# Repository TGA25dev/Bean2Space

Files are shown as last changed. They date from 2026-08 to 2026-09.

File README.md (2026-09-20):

# Bean2Space 🚀
> HRC-01: the first rocket of the Bean2Space program. A 3D printed DIY rocket powered by an ESP32-S3 flight computer running MicroPython. Featuring telemetry logging, a ground station and a trigger system.<br><br>
Also my submission to the [Stardance Challenge](https://stardance.hackclub.com/)!

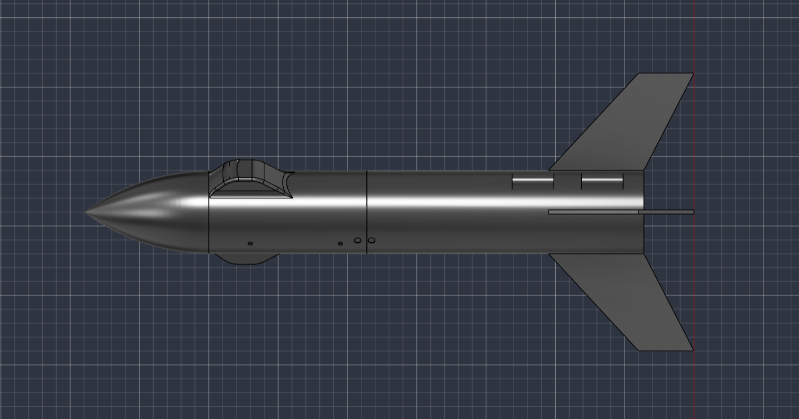
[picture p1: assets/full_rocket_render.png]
Banner


## Overview
This project is basically made of three main components:
- **The flight computer**: An ESP32-S3 running micropython. Reads temperature and pressure from the BMP280 and gyroscope/accelerometer data from an MPU6050. Both via I2C. Also transmits live telemetry to the ground station using ESPNOW protocol. *In other terms : the brain of this project*
- **The ground station**: A simple ESP32-C3 that receives the telemetry packets and logs them *(more features to come later)*
- **The trigger Station**: A wired ignition trigger. Uses AA batteries, a safety key and a *red* trigger button.

## CAD and Hardware Design
### Source files and visuals
> All the CAD work has been done in **Fusion 360** but some initial .obj files have been imported from **[OpenRocket](https://openrocket.info/)**. 

- **Nose cone + bottom closure:**<br>
The nose cone has a hole on the bottom to add extra weight if ever needed. The bottom closure part closes the hole and is sealed using tape.

   [Download nose_cone.step](cad/rocket/nose_cone.step)
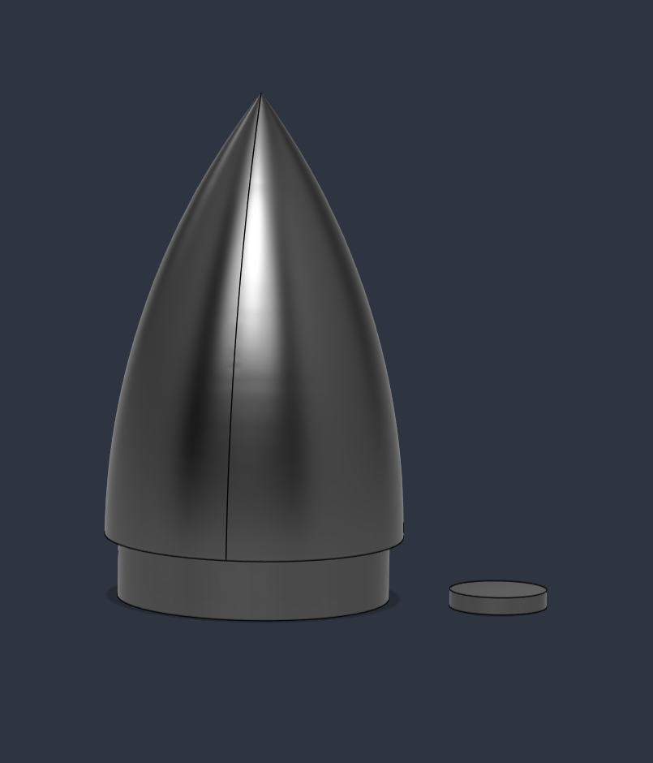
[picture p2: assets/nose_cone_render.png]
nose_cone_file
   

---

- **Main Stage**:<br>
The main stage has two pods on both sides to add a small camera (SQ11 size), M3 screw holes to attach the inner rack (see below) with guide rails inside, 3 static port holes and finally an alignment hole to properly align main and engine stage.

   [Download main_stage.step](cad/rocket/main_stage.step)
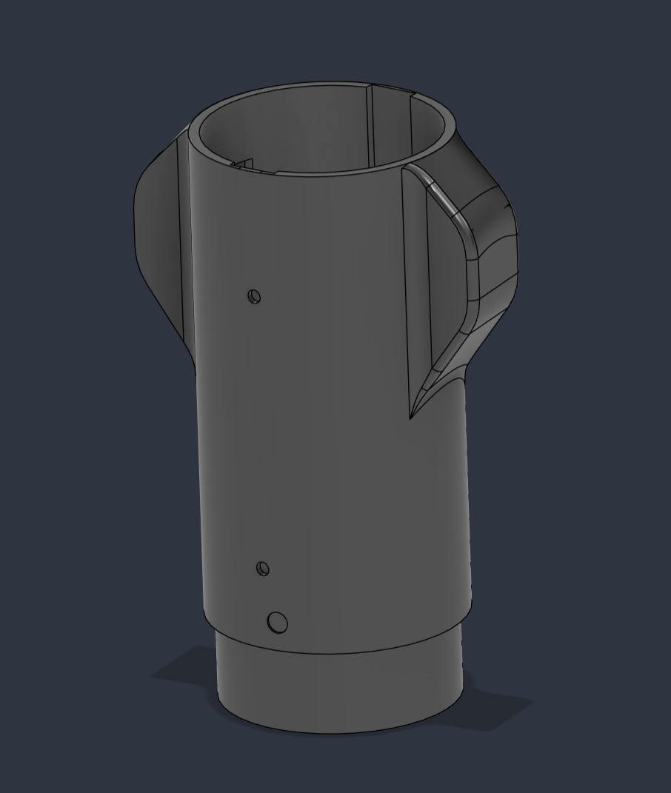
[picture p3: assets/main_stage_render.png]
main_stage_file
   

---

- **Instruments Rack**:<br> 
The rack is slid in the stage's guide rails and secured with 4 M3 screws on the sides using inserts. The board is placed on one side and also secured with M3 screws while on the other side is the battery slot secured with velcro. On top there's a small handle to easily pull off the rack from the rocket.

   [Download instruments_rack.step](cad/rocket/instruments_rack.step)
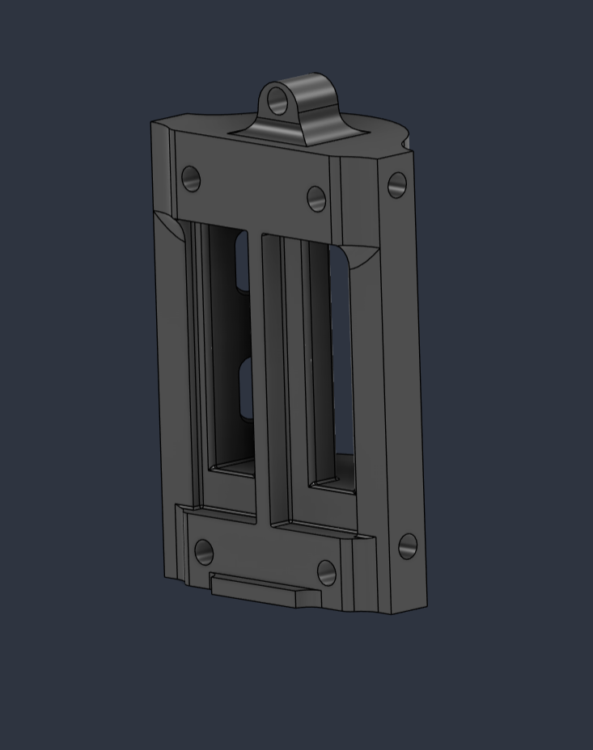
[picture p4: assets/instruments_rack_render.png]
instruments_rack_file
   

---

- **Shock Cord Mount**:<br>
Two of those mounts are placed on the bottom of the main stage shoulder and glued with epoxy. A long screw is slid between both holes with a nut at the end. Finally the shock cord is tied to the screw.

   [Download shock_cord_mount.step](cad/rocket/shock_cord_mount.step)
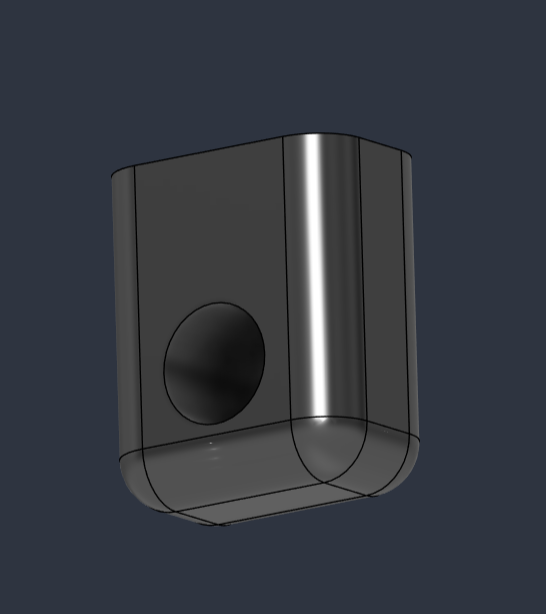
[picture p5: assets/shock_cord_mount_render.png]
shock_cord_mount_file
   

---

- **Engine Stage**:<br>
The engine is slid in the 18mm hole on the bottom. The stage has two 6mm diameter launch lugs where you can slide the launch rod. On the bottom in the inside of the tube 4 holes allow you to tie the shock cord.

   [Download engine_stage.step](cad/rocket/engine_stage.step)
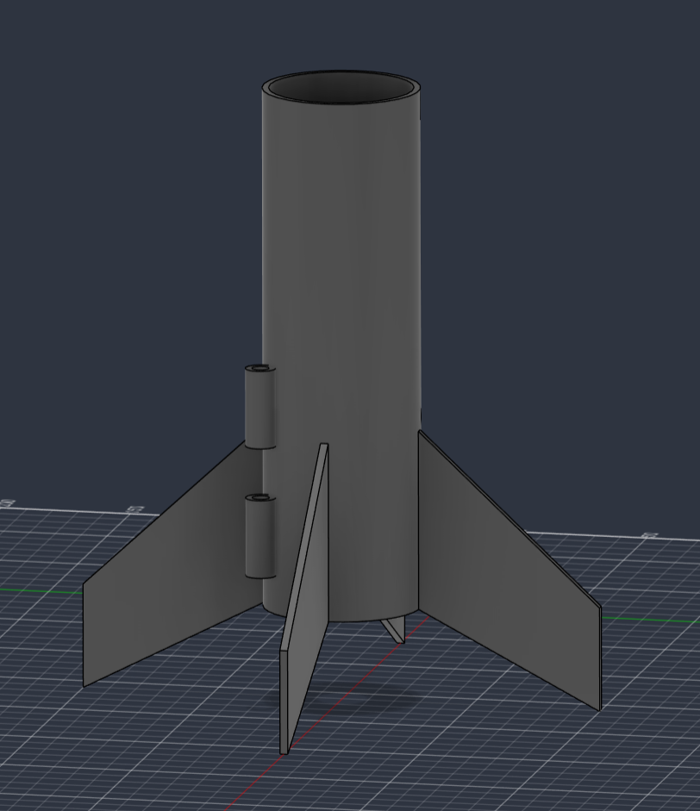
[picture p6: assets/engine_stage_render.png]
engine_stage__file
   

---

- **Trigger Box Cover**:<br>
Here there are 3 holes, one for an led, another for the security key and a third one for the launch button.

   [Download trigger_box_cover.step](cad/trigger_station/trigger_box_cover.step)
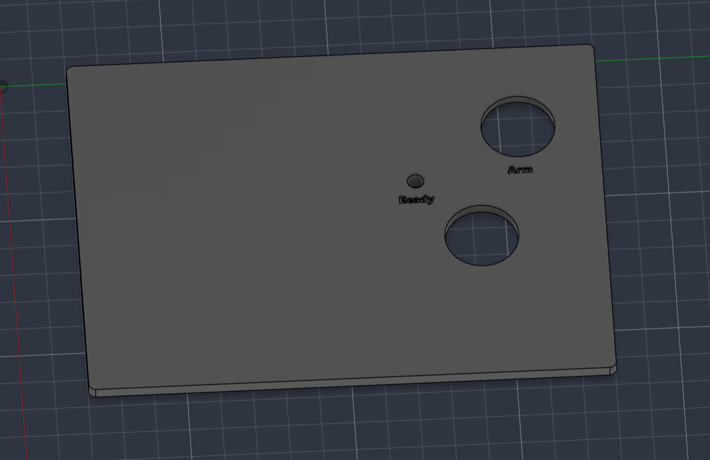
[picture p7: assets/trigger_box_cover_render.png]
trigger_box_cover
   

---

- **Trigger Box Body**:<br>
The box has a support to add velcro to it and put the two battery holders. It also has a hole to fit the ignition cable through it.

   [Download trigger_box_body.step](cad/trigger_station/trigger_box_body.step)
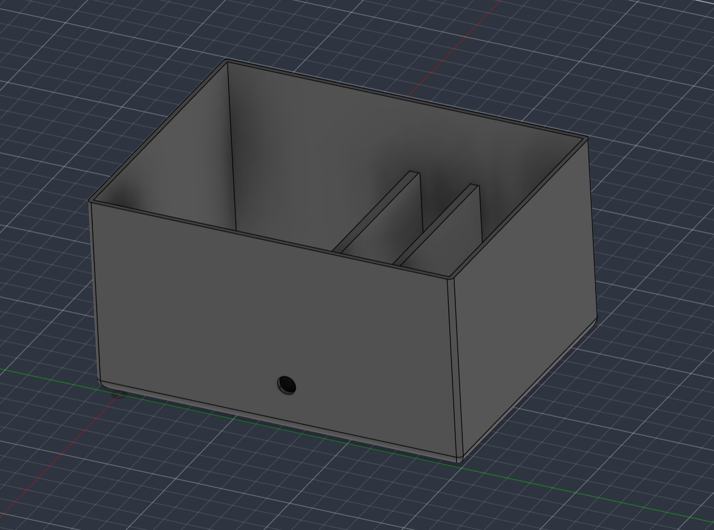
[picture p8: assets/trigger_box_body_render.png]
trigger_box_body
   

### Wiring diagrams

### Flight computer
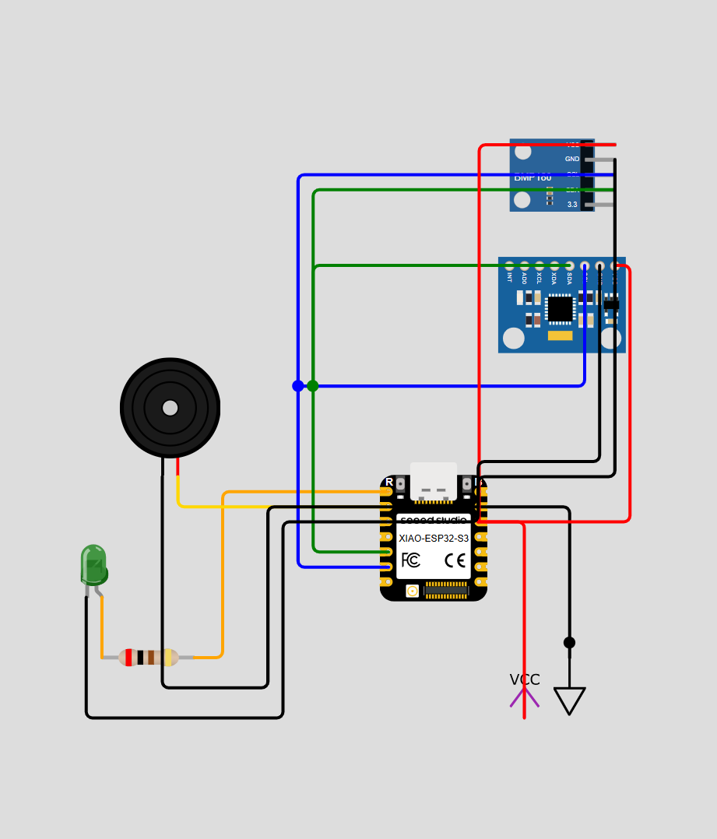
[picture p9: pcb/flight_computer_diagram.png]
flight_computer_diagram


| Component | Component Pin | ESP32 Pin |
| :--- | :--- | :--- |
| **BMP280 & MPU6050** | VCC | 3.3V |
| | GND | GND |
| | SDA | GPIO5 (D4) |
| | SCL | GPIO6 (D5) |
| **Buzzer** | Signal (+) | GPIO4 (D3) |
| | (-) | GND |
| **Status LED** | Anode (+) | GPIO1 (D0) |
| | (-) | GND |

### Trigger Station
trigger_station_diagram

## Firmware 
Both the ESP32 S3 and C3 run MicroPython. Use [`esptool`](https://docs.espressif.com/projects/esptool/en/latest/esp32/) to flash them.

1. Flash the correct MicroPython version for each of the boards
2. - **ESP32-S3 (flight computer):** Upload everything in the `/firmware` folder onto the board (if possible don't upload the `/ground_station` folder as it will be useless for this board).

   - **ESP32-C3 (ground station)**: Upload all the files in `/software/ground_station` onto the board. Once uploaded release the COM port by closing the connection. Then open a PowerShell terminal and run `python -m serial.tools.miniterm COM(add here the correct port number) 115200`. You might need to install the `serial` module. <br>*Note: If nothing appears on screen try pressing CTRL+D to soft reset the connection*

## BOM

| Item Name | Qty | Notes |
| :--- | :---: | :--- |
| **BMP280 Sensor** | 1 | Module for measuring temperature and pressure in the rocket |
| **Buzzer** | 1 | A classic buzzer |
| **Green LED** | 1 | LEDs |
| **Seeed XIAO ESP32-S3** | 1 | Main microcontroller for the rocket |
| **MPU6050 Accelerometer/Gyro** | 1 | Accelerometer and gyro |
| **220Ω Resistor** | 1 | Well that's a resistor.. |
| **MicroSD Module** | 1 | To store data directly in flight |
| **LiPo Battery 3.7V 550mAh** | 2 | One to power the rocket and another for backup |
| **Seeed XIAO ESP32-C3** | 1 | Microcontroller for the ground station in charge of receiving telemetry data |
| **BCS050 Prototype Board** | 1 | To solder the components of the flight computer |
| **JST SYP Adapter** | 1 | To connect the battery to the microcontroller in the rocket |
| **AA Battery Holder** | 2 | To power the trigger station and ignite the rocket engine |
| **HP Cable (12 meters)** | 12 | To connect the trigger station to the rocket engine (usually sold per 1 meter) |
| **Black Crocodile Clip** | 1 | To connect the cable to the rocket engine electric igniters |
| **Red Crocodile Clip** | 1 | Same as above |
| **Security Key Switch** | 1 | A security key switch to turn on the trigger station and prevent accidental ignition |
| **Red Trigger Button** | 1 | To trigger the rocket engine ignition |
| **1/2W 1kΩ Resistors (Pack of 5)** | 5 | To limit the current in the trigger station |
| **Klima D9-5 Rocket Engines (Pack of 6)** | 6 | Well, that's the rocket engines... qty is 6 because they usually don't sell them separately|
| **Kevlar Cord (2 meters)** | 2 | Shock cord to connect the rocket tubes to the parachute (usually sold per 1 meter)|
| **22x22cm Nomex Parachute Protector** | 1 | To protect the parachute from the rocket engine heat (parachute will be put inside that) |
| **Klima Launch Pad Kit** | 1 | This is a launchpad kit |
| **6mm Launch Rod** | 1 |  The kit above already includes a launch rod, but it's too short and not stable enough for a rocket of this size

*Note: Last 5 items have been found on [SierraFox Hobbies](https://sierrafoxhobbies.com) website.*

### Full file with more details and information is available [here](BOM.csv).

## Why is it called like that ?
Well it's some kind of private joke with some of my friends, final goal of the project would be to actually put a bean in the rocket..

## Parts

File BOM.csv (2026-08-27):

Item Name | Qty | Price (total) (USD) | Price (total) (EUR) | Item link | Notes
BMP280 | 1 | $5.18 | €4.50 | https://www.gotronic.fr/art-module-bmp280-ky052-29155.htm | Module for measuring temperature and pressure in the rocket
Buzzer | 1 | $1.61 | €1.40 | https://www.gotronic.fr/art-buzzer-sv1407-21014.htm | A classic buzzer
Green LED Pack (pack of 10) | 1 | $0.81 | €0.70 | https://www.gotronic.fr/art-leds-vertes-led5gl-360.htm | ED's
XIAO ESP32-S3 | 1 | $9.90 | €8.60 | https://www.gotronic.fr/art-carte-xiao-esp32s3-36954.htm | Main microcontroller for the rocket
MPU6050 | 1 | $6.67 | €5.80 | https://www.gotronic.fr/art-module-6-dof-sen-mpu6050-31492.htm | Accelerometer and gyro
220 ohm Resistor | 1 | $0.12 | €0.10 | https://www.gotronic.fr/art-resistance-carbone-1w-220-8486-2741.htm
microSD Module | 1 | $8.49 | €7.38 | https://www.gotronic.fr/art-module-carte-micro-sd-dev-13743-24810.htm | To store data direcly on the rocket so I have multiple backcups (on rocket and on laptop connected to the ground station)
Accu LiPo 3.7 Vcc 550 mAh Battery | 2 | $16.11 | €14.0 | https://www.gotronic.fr/art-accu-lipo-3-7-vcc-550-mah-l503040-31712.htm | One to power the rocket and another for backup
XIAO ESP32-C3 | 1 | $6.79 | €5.90 | https://www.gotronic.fr/art-carte-xiao-esp32c3-35643.htm | Microcontroller for the ground station in charge of receiving telemetry data
50x100 BCS050 soldering board | 1 | $1.38 | €1.20 | https://www.gotronic.fr/art-plaque-d-essais-bcs050-6931.htm | To solder the components of the flight computer
JST SYP to JSTSYP2P adapter | 1 | $0.40 | €0.35 | https://www.gotronic.fr/art-conn--jst-syp-2p-lipo-47807.htm | To connect the battery to the microcontroller in the rocket
AA Battery Holder | 2 | $6.22 | €5.4 | https://www.gotronic.fr/art-coupleur-4-piles-lr6-aa-bf4xaa-31559.htm | To power the trigger station and ignite the rocket engine
HP CC075RN Cable (per 1 meter) | 12 | $8.29 | €7.2 | https://www.gotronic.fr/art-cable-hp-cc075rn-5087.htm | To connect the trigger station to the rocket engine (12meters so we can be far away when it ignites)
Black Crocodile Clip | 1 | $0.40 | €0.35 | https://www.gotronic.fr/art-pince-crocodile-rk01n-4696.htm | To connect the cable to the rocket engine electric igniters
Red Crocodile Clip | 1 | $0.40 | €0.35 | https://www.gotronic.fr/art-pince-crocodile-rk01r-4697.htm | Same as above
Security Key Switch | 1 | $6.35 | €5.50 | https://www.gotronic.fr/art-inter-a-cle-2-positions-40374.htm | A security key switch to turn on the trigger station and prevent accidental ignition
Red Trigger Button | 1 | $9.80 | €8.5 | https://www.gotronic.fr/art-bp-affleurant-lumineux-40376.htm | To trigger the rocket engine ignition (led won't work but I'v chose this one because it has the same diameter as the key switch and I don't have to solder anything)
1/2W 1k Resistor (pack of 5) | 1 | $0.35 | €0.30 | https://www.gotronic.fr/art-5-resistances-1-2w-1-0-k-8486-2659.htm | To limit the current in the trigger station
Klima D9-5 Rocket Engine (pack of 6) | 1 | $40.86 | €35.50 | https://www.sierrafoxhobbies.com/fr/1394-moteurs-klima-d9-5.html | Well thats the rocket engines..
Kevlar Cord (per 1 meter) | 2 | $3.45 | €3.0 | https://www.sierrafoxhobbies.com/fr/2375-cordon-kevlar-2-mm.html | Shock cord to connect the rocket tubes to the parachute
22x22cm Nomex Parachute protector | 1 | $12.08 | €10.50 | https://www.sierrafoxhobbies.com/fr/1956-nomex-22x22-protecteur-de-parachute.html | To protect the parachute from the rocket engine heat (parachute will be put inside that)
Launch Pad Kit | 1 | $30.57 | €26.50 | https://www.sierrafoxhobbies.com/fr/1535-rampe-de-lancement-klima.html | This is a launchpad kit I initially thought I could make it myself but I think it will be safer and easier to but it already made; it includes a launchpad and a deflector plate to protect the ground from the rocket's engine heat
Launch Rod | 1 | $8.06 | €6.99 | https://www.sierrafoxhobbies.com/fr/1594-tige-de-lancement-6-mm.html | The kit above already includes a launch rod but it's too short and and not stable enough for a rocket of this size
Kapton Tape | 1 | $5.14 | €5.99 | https://www.amazon.fr/dp/B0FS2CK2NM?ref=ppx_yo2ov_dt_b_fed_asin_title | To protect some parts of the rocket from heat and to insulate some wires
Shipping Fees for Gotronic Shop | 1 | $6.84 | €5.90 | https://www.gotronic.fr/ | Shipping Fees for Gotronic Shop
Shipping Fees for Sierra Fox Hobbies Shop | 1 | $27.81 | €24.0 | https://www.sierrafoxhobbies.com/ | Shipping Fees for Sierra Fox Hobbies Shop
Total Price (USD): | $187.86 | Total Price (EUR): €162.92 |  |  | EUR prices have been converted to USD using exchange rate of 1 EUR = 1.15 USD.

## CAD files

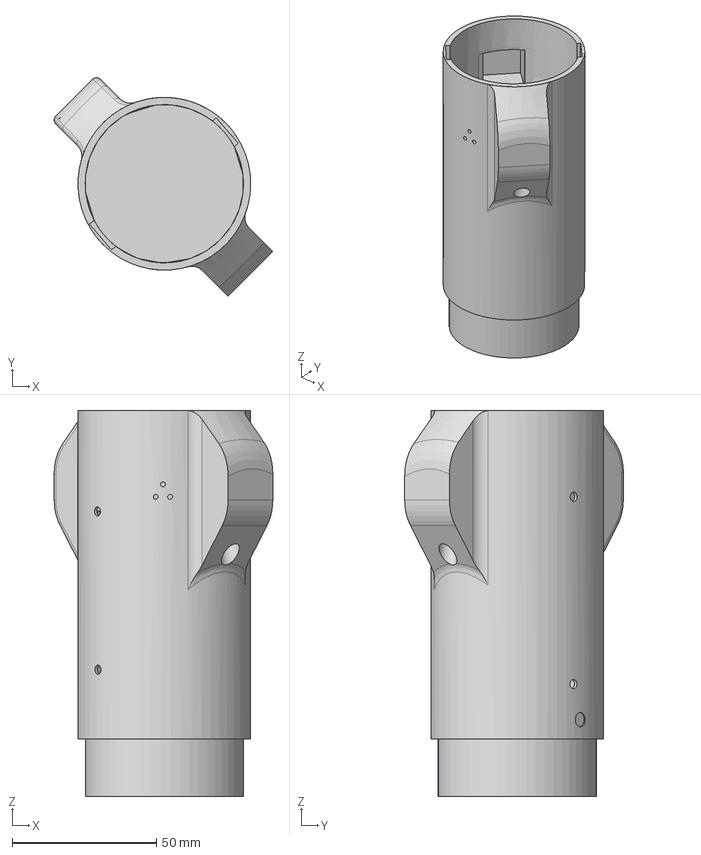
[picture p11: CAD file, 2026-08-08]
cad/rocket/main_stage.step
75.9 x 75.9 x 134.0 mm

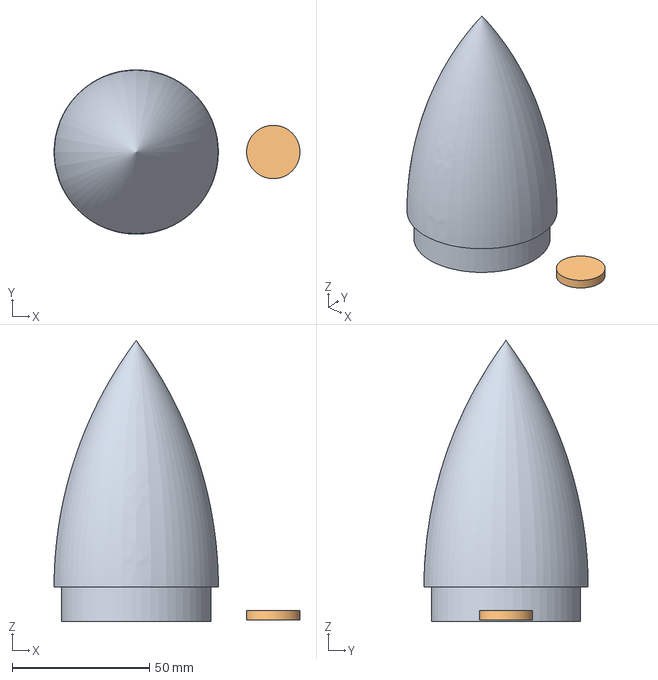
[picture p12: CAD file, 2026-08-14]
cad/rocket/nose_cone.step
89.7 x 60.0 x 102.5 mm

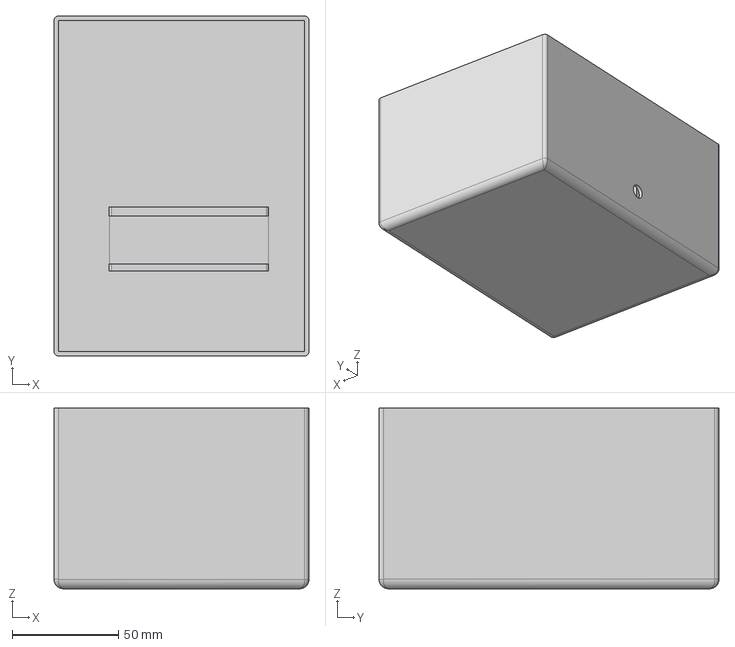
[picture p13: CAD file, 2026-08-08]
cad/trigger_station/trigger_box_body.step
120.0 x 160.0 x 85.0 mm

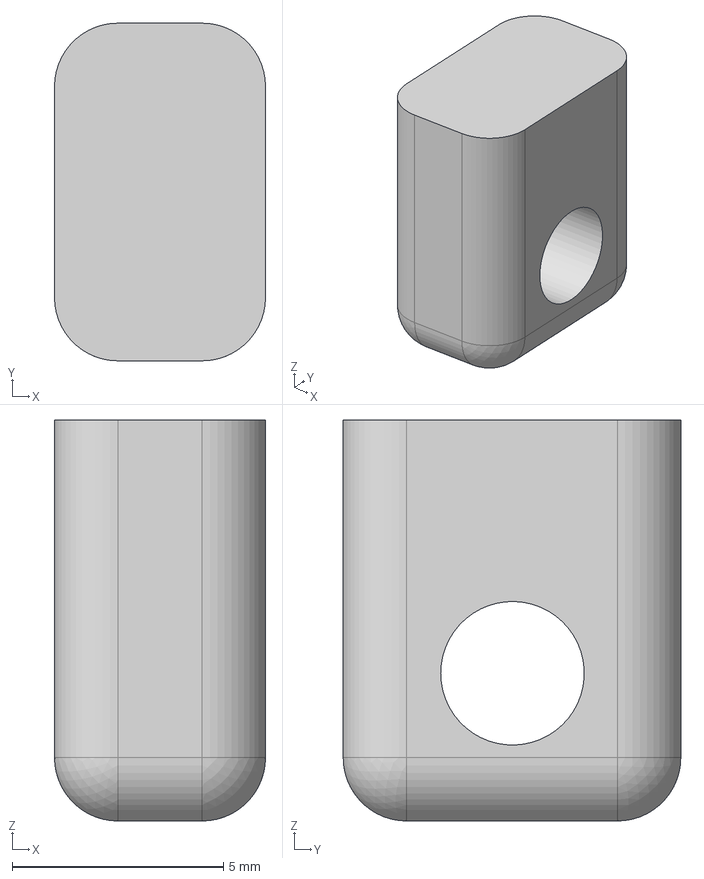
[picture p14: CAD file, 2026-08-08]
cad/rocket/shock_cord_mount.step
5.00 x 8.00 x 9.50 mm

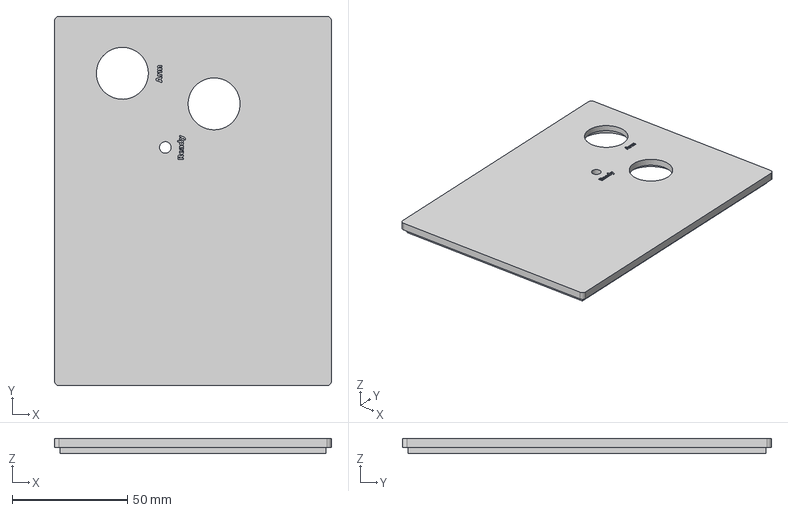
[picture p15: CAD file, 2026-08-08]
cad/trigger_station/trigger_box_cover.step
120.0 x 160.0 x 6.50 mm

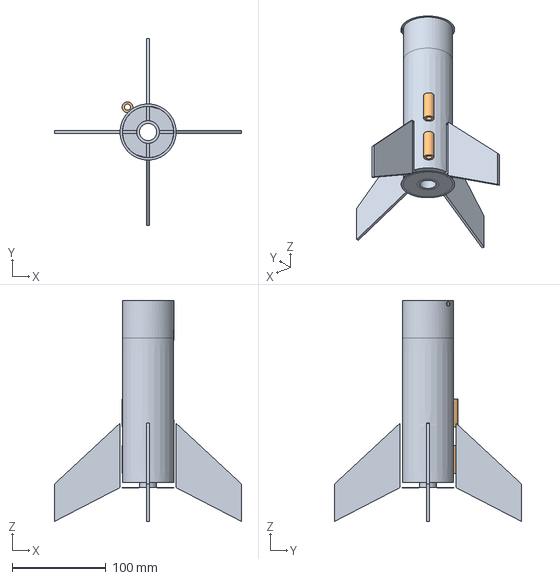
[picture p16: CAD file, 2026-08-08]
cad/rocket/engine_stage.step
200.0 x 200.0 x 236.2 mm

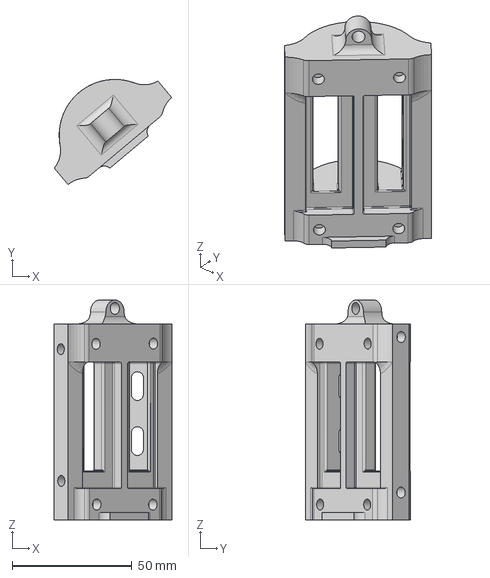
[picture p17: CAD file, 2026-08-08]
cad/rocket/instruments_rack.step
49.2 x 44.0 x 92.0 mm

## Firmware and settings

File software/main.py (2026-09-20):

import time
import random
import machine

from software.utils.buzzer_manager import BuzzerManager
buzzer = BuzzerManager(4) #pin 4

from software.utils.led_manager import LEDManager
onboard_led = LEDManager(1) #LED on pin 1

from software.utils.wifi_manager import start_access_point, check_for_connections, setup_web_server, handle_web_request, stop_access_point
from software.modules.calibration import calibrate_sensors
from software.modules.telemetry import get_telemetry
from software.modules.esp_now import send_telemetry, send_message, start_wireless_transmiter

from software.utils.internal_temp_manager import read_internal_temp, check_internal_temp

from software.modules.state_manager import RocketState

machine.freq(160000000)

ground_station_mac = b'X\x8c\x81\xae\x16\xb0'
calibrated = False
esp_now_ready = False
esp_now_should_start = False
ap_should_stop = False
telemetry = None
transmitter = None

telemetry_sequence_number = 0
message_sequence_number = 0

timestamp = 0.0
_last_tick = time.ticks_ms()

flight_id = random.randint(1000, 9999)
rocket = RocketState()

ground_pressure = 0.0
imu_offsets = {
    "ay": 0.0,
    "ax": 0.0,
    "az": 0.0,
    "gx": 0.0,
    "gy": 0.0,
    "gz": 0.0
}

def send_live_log(text, level="INFO"):
    """
    Sends a live log message to the ground station using the ESPNow protocol
    
    args:
        sender (espnow.ESPNow): ESPNow sender object
        text (str): the log message to be sent
        level (str): the log level (INFO, WARNING, ERROR)

    returns:
        bool: Indicates if the log message was sent successfully or not
    """

    global timestamp, flight_id, ground_station_mac, esp_now_ready, transmitter, message_sequence_number

    #print(esp_now_ready, transmitter)

    if not esp_now_ready or transmitter is None:
        print("ESPNow is not ready! Cannot send log message")
        return False

    message = f"[{level}]:{text}"
    message_sequence_number += 1
    sent_msg = send_message(transmitter, ground_station_mac, message, timestamp, flight_id, message_sequence_number, rocket.state)

    return sent_msg

def update_system_clock() -> None:
    """
    Updates the global timestamp variable based on the elapsed time since the last update

    args:
        None

    returns:
        None
    """
    global timestamp, _last_tick
    
    current_tick = time.ticks_ms()
    
    ms_passed = time.ticks_diff(current_tick, _last_tick)   #how many milliseconds passed since the last loop iteration
    
    timestamp += ms_passed / 1000.0 #converted to seconds

    _last_tick = current_tick

def handle_state_event(event:str):
    if event == "ARMED":
        send_live_log("Rocket is armed and ready for launch!", "INFO")

    elif event == "LAUNCH_DETECTED":
        send_live_log("Launch detected! Rocket is in flight!", "INFO")

    elif event == "APOGEE_DETECTED":
        send_live_log(f"Apogee detected! Apogee at {rocket.max_altitude}m !", "INFO")
        buzzer.on()
        time.sleep(0.2)
        buzzer.off()

    elif event == "TOUCHDOWN_DETECTED":
        send_live_log("Touchdown detected!", "INFO")

def apply_calibration() -> None:
    """
    Performs the calibration process and updates the global variables for ground pressure and IMU offsets

    args:
        None
    returns:
        None
    """

    global ground_pressure, imu_offsets, calibrated
    ground_pressure, imu_offsets = calibrate_sensors()
    calibrated = True

    time.sleep(0.5)
    print("Calibration complete! System Armed.")
    for _ in range(2):
        buzzer.on()
        onboard_led.on()
        time.sleep(0.15)
        buzzer.off()
        onboard_led.off()
        time.sleep(0.25)


def power_up() -> None:
    """
    Performs the power-up sequence

    args:
        None

    returns:
        None
    """

    global ground_pressure, calibrated, imu_offsets
    global esp_now_should_start, ap_should_stop
    global ground_station_mac, esp_now_ready ,timestamp, flight_id, transmitter, telemetry_sequence_number
    print(f"Powering up the system... (ID: {flight_id})")

    onboard_led.on()
    buzzer.on()
    time.sleep(0.2)
    
    buzzer.off()
    time.sleep(0.3)
    onboard_led.off()
    time.sleep(0.3)
    
    for _ in range(2):
        onboard_led.on()
        time.sleep(0.3)
        onboard_led.off()
        time.sleep(0.3)

    onboard_led.off()
    print("Greeting sequence completed !")

    print("Starting Wi-Fi Access Point...")
    wifi_access_point = start_access_point() 
    print(f"Access Point started successfully!")

    wait_for_connections_printed = True #print flag
    while not check_for_connections(wifi_access_point): #while no device is connected
        
        for _ in range(2):
            onboard_led.on()
            time.sleep(0.2)
            onboard_led.off()
            time.sleep(0.2)

        if wait_for_connections_printed:
            print("Waiting for devices to connect...")
            wait_for_connections_printed = False
        
        time.sleep(1)
    
    print("Device connected to the Access Point!")
    onboard_led.off()
    print("Starting web server...")

    server_socket = setup_web_server()  #initialize once the webserver socket
    print("Web server ready!")
    onboard_led.on()
    buzzer.on()
    time.sleep(0.3)
    buzzer.off()
    onboard_led.off()

    print("System is fully operational! Starting main loop...")

    while True:
        if not calibrated: #calibrate if not done yet
            time.sleep(1.5)

            apply_calibration()

        if calibrated:
            telemetry = get_telemetry(imu_offsets, ground_pressure)
            #print(telemetry)

        web_command = handle_web_request(server_socket)
        if web_command == "start-esp-now":
            esp_now_should_start = True
            ap_should_stop = True

        elif web_command == "stop-ap":
            ap_should_stop = True
            
        elif web_command == "calibrate":
            apply_calibration()

        if ap_should_stop or esp_now_should_start: #check if state change was requested by the web panel
            print("Web command received: stopping Wi-Fi access point")
            time.sleep(0.1)
            
            try:
                server_socket.close() #close webserver first
            except:
                pass
                
            stop_access_point(wifi_access_point)
            break  #stop server

        update_system_clock()
        time.sleep(0.05)

        time.sleep(0.5)

    if esp_now_should_start:
        print("Starting ESPNOW transmitter...")
        try:
            transmitter = start_wireless_transmiter(ground_station_mac)
            print("ESPNOW transmitter initialized")
            esp_now_ready = True

        except Exception as error:
            print("ESPNOW startup failed:", repr(error))
            buzzer.on()
            time.sleep(1)
            buzzer.off()
            raise

        print("Entering Flight Mode... Telemetry will be sent to the ground station")
        print("Starting internal temperature monitoring...")

        for _ in range(3):
            onboard_led.on()
            buzzer.on()
            time.sleep(0.25)
            onboard_led.off()
            buzzer.off()
            time.sleep(0.25)
    else:
        print("System entered passive holding mode. Standing by...")

    wdt = machine.WDT(timeout=5000) #5s watchdog timer

    while True:
        if esp_now_ready and calibrated:
            
            telemetry = get_telemetry(imu_offsets, ground_pressure, demo=False)

            acceleration = (
                telemetry["accel_x"],
                telemetry["accel_y"],
                telemetry["accel_z"]
            )
            event = rocket.update(telemetry["altitude"], calibrated, acceleration=acceleration)
            
            if event:
                handle_state_event(event)

            telemetry_sequence_number += 1
            sent = send_telemetry(transmitter, ground_station_mac, telemetry, timestamp, flight_id, telemetry_sequence_number, rocket.state)
            if not sent:
                print("Radio transmission failed!")
        
        internal_temp_thresold_exceeded, current_temp = check_internal_temp(85.0) #thresold of 85C

        #DEBUG
        #print(f"Internal temperature: {current_temp:.2f}C")
        #print(event, telemetry["altitude"], acceleration, rocket.state)
        #print(f"[{timestamp}] Flight Telemetry: {telemetry}")
        #END DEBUG

        if not internal_temp_thresold_exceeded and current_temp >= 75.0:
            print(f"WARNING: Internal temperature is getting high ({current_temp:.2f}C)!")
            send_live_log(f"Internal temperature is getting high ({current_temp:.2f}C)!", "WARNING")

        elif internal_temp_thresold_exceeded:
            print("WARNING: Internal temperature exceeds threshold! ({current_temp:.2f}C) System may be overheating!")
            send_live_log("Internal temperature exceeds threshold! ({current_temp:.2f}C) System may be overheating!", "WARNING")

        wdt.feed() #reset watchdog timer
        update_system_clock()
        time.sleep(0.1) #10Hz sampling rate 

power_up() #starts main sequence

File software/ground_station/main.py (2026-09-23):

import espnow #type: ignore
import network
import wifi
import time

time.sleep(3)

print("\n" + "="*40)
print("SYSTEM BOOT: ground station started!")
print("="*40 + "\n")

wifi.reset(sta=True, ap=False, channel=6) #start wifi in station mode (channel 6) and disable AP mode

wlan = network.WLAN(network.STA_IF)
wlan.config(protocol=network.MODE_LR) #type: ignore #enable LR Mode

print("Ground station MAC:", wlan.config("mac"))
print("Ground station Wi-Fi channel:", wlan.config("channel"))

receiver = espnow.ESPNow()
receiver.active(True)

#create a pre allocated storage list to grab the RSSI
telemetry_packet = [bytearray(6), bytearray(250), 0, 0] # [mac_address, message_buffer, rssi, timestamp]

print("Ground Stations is active! Waiting for telemetry packets...")

last_telemetry_sequence = None
last_message_sequence = None

while True:
    #check if a packet is waiting in the radio stack
    if receiver.any():
        try:
            # recvinto extracts data directly into the list, captures RSSI automatically
            length = receiver.recvinto(telemetry_packet)
            
            if length > 0:
                #extract components from our pre allocated list :
                sender_mac = telemetry_packet[0]
                raw_msg = telemetry_packet[1][:length] #trim buffer to the true message length
                rssi = telemetry_packet[2]             #signal strength in dBm
                
                #decode and print data payload
                data_payload = raw_msg.decode('utf-8')

                try:
                    parts = data_payload.split(",")

                    timestamp = parts[0]
                    packet_type = parts[1]
                    sequence_number = int(parts[2])
                    flight_state = parts[3]
                    flight_id = parts[4]
                    sequence = sequence_number

                    if packet_type == "telemetry":
                        if len(parts) != 16:
                            raise ValueError("Invalid telemetry packet")

                        (
                            timestamp,
                            packet_type,
                            sequence_number,
                            flight_state,
                            flight_id,
                            temperature,
                            absolute_pressure,
                            relative_pressure,
                            altitude,
                            accel_x,
                            accel_y,
                            accel_z,
                            gyro_x,
                            gyro_y,
                            gyro_z,
                            temp_imu,
                        ) = parts

                        if last_telemetry_sequence is not None:
                            missing = sequence - last_telemetry_sequence - 1
                            
                            if missing > 0:
                                print(f"{missing} telemetry packets missing ! (last seq: {last_telemetry_sequence}, current seq: {sequence})")

                        last_telemetry_sequence = sequence

                        data_string = f"{timestamp},{packet_type},{sequence_number},{rssi},{flight_state},{flight_id},{temperature},{absolute_pressure},{relative_pressure},{altitude},{accel_x},{accel_y},{accel_z},{gyro_x},{gyro_y},{gyro_z},{temp_imu}"
                        print(data_string)
                        
                    elif packet_type == "message":
                        if len(parts) < 6:
                            raise ValueError("Invalid message packet")

                        message = ",".join(parts[5:])

                        if last_message_sequence is not None:
                            missing = sequence - last_message_sequence - 1
                            if missing > 0:
                                print(f"WARNING: {missing} message packets missing (last seq: {last_message_sequence}, current seq: {sequence})")

                        last_message_sequence = sequence

                        message_string = f"{timestamp},{packet_type},{sequence_number},{rssi},{flight_state},{flight_id},{message}"
                        print(message_string)

                    else:
                        print(f"WARNING | Timestamp: {timestamp} | Unknown packet type '{packet_type}' received. Raw data: {data_payload} | Signal: {rssi}dBm")

                except ValueError as e:
                    print("ERROR Packet parsing warning:", e)
                
        except Exception as err:
            print("ERROR Packet parsing warning:", err)
            
    time.sleep_ms(5) #tiny delay to allow other tasks to run

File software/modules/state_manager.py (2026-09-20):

import time 
import math

class RocketState:
    def __init__(self):
        self.state = "standby"
        self.filtered_altitude = 0.0
        self.last_altitude = 0.0
        self.last_time_ms = None
        self.velocity = 0.0
        self.max_altitude = 0.0

        self.launch_count = 0
        self.apogee_count = 0
        self.landed_count = 0

    def update(self, altitude, calibrated=True, now_ms=None, acceleration=(0.0, 0.0, 0.0)):
        if now_ms is None:
            now_ms = time.ticks_ms()

        self._update_motion(altitude, now_ms)

        if self.state == "standby":
            if calibrated:
                self.state = "armed"
                return "ARMED"

        elif self.state == "armed":
            acceleration_magnitude = math.sqrt(
                acceleration[0] ** 2
                + acceleration[1] ** 2
                + acceleration[2] ** 2
            )
            altitude_triggered = self.filtered_altitude > 2.0
            acceleration_triggered = acceleration_magnitude > 1.5

            if altitude_triggered or acceleration_triggered:
                self.launch_count += 1
            else:
                self.launch_count = 0

            if self.launch_count >= 2: #if either trigger is active for 2 consecutive reads
                self.state = "flight"
                self.max_altitude = self.filtered_altitude
                return "LAUNCH_DETECTED"

        elif self.state == "flight":
            self.max_altitude = max(self.max_altitude, self.filtered_altitude)

            descending = self.velocity <= 0.2

            dropped_from_peak = (self.max_altitude - self.filtered_altitude) > 1.5 #if dropped more than 1.5m from peak alt it means its descending

            if descending and dropped_from_peak:
                self.apogee_count += 1

            else:
                self.apogee_count = 0

            if self.apogee_count >= 3: #if descending and dropped from peak for 3 consecutive reads apogee has been reached
                self.state = "descent"
                return "APOGEE_DETECTED"

        elif self.state == "descent":
            stable_near_ground = (self.filtered_altitude < 2.5 and abs(self.velocity) < 0.3) #if below 2.5m and velocity is low means it has landed

            if stable_near_ground:
                self.landed_count += 1

            else:

                self.landed_count = 0

            if self.landed_count >= 15: #landed for 15 reads

                self.state = "landed"
                return "TOUCHDOWN_DETECTED"

        return None

    def _update_motion(self, altitude, now_ms):
        if self.last_time_ms is None:
            self.filtered_altitude = altitude

        else:
            self.filtered_altitude = (self.filtered_altitude * 0.7+ altitude * 0.3) #filtered to reduce noise

            delta_ms = time.ticks_diff(now_ms, self.last_time_ms)

            if delta_ms > 0:
                raw_velocity = (self.filtered_altitude - self.last_altitude) / (delta_ms / 1000.0) #velocity in m/s

                self.velocity = (self.velocity * 0.8 + raw_velocity * 0.2) #filtered velocity

        self.last_altitude = self.filtered_altitude
        self.last_time_ms = now_ms

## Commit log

2026-06-20 feat: add led and buzzer manager files for easy use of both components
2026-06-20 feat: add calibration module and telemetry getter module
2026-06-24 feat: add some buttons on dashboard for basic actions like calibration and buzzer testing
    [wifi_manager.py]
2026-06-24 feat: add basic code from ground station listener
2026-06-25 fix: fix relative pressure calculation and acceleration axis that were wrong
    [calibration.py, telemetry.py]
2026-06-25 feat: add telemetry transmission to ground station; add new buttons to dashboard; improve main system loop logic
2026-06-25 feat: replace counter and packet id by a timestamp value using a global clock
    [esp_now.py, ground_station.py, main.py]
2026-06-26 feat: add flight id to wireless transmission and add message types (telemetry or message) for better identification
2026-06-26 misc: small change in print message
2026-06-26 fix: improve socket creation by killing zombie connections before starting a new one
    [wifi_manager.py]
2026-06-26 fix: adjust chip clock frequency
    [main.py]
2026-07-12 feat: implement rocket state management based on altitude and velocity
2026-07-12 feat: add live logging function to send live logs to the ground station using espnow
2026-08-01 fix: fix variable name typo in ground station print statement
    [ground_station.py]
2026-08-08 chore: rename ground station file to main.py
2026-08-08 feat(cad): add initial cad files
    [components_rack.step, engine_stage.step, main_stage.step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]
2026-08-08 feat: add BOM.csv file
    [BOM.csv]
2026-08-14 fix: fix BOM.csv linting issues and modify product description
    [BOM.csv]
2026-08-14 fix: fix some items qty in bom file and update some names and descriptions
    [BOM.csv]
2026-08-14 chore: rename file name and upload new version of nose cone .step file
    [instruments_rack.step, nose_cone.step]
2026-08-18 fix: update wrong shipping fees and total price in BOM file
    [BOM.csv]
2026-08-27 fix: add descent mock data to telemetry module demo mode
    [telemetry.py]
2026-08-27 fix: update BOM file
    [BOM.csv]
2026-08-27 fix: update product url in bom file
    [BOM.csv]
2026-08-28 fix: fix bug where calibration offsents were not applied after manual calibration on dashboard
    [main.py, wifi_manager.py]
2026-09-19 feat: add disabled parameter to buzzer and led
    [main.py]
2026-09-19 feat: add internal temperature monitoring and alerts
2026-09-19 fix: adjust led timings in multiple sequences
    [main.py]
2026-09-20 fix: update buzzer pin assignments to pin 4 across multiple files
    [calibration.py, main.py, wifi_manager.py]
2026-09-20 fix: correct calibration offset for accelerometer y-axis by removing gravity adjustment
    [calibration.py]
2026-09-20 feat: enhance event handling with buzzer feedback and improve web request command handling
    [main.py, wifi_manager.py]
2026-09-23 fix: add main.py file to allow boot mode to be interrupted before starting script
    [main.py]
2026-09-24 feat: implement telemetry data collection by serial connection and CSV logging from ground station
